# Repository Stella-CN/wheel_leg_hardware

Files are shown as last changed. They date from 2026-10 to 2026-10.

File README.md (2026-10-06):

# wheel_leg_hardware — 轮腿机器人硬件工程

本工程保存完整机器人机械与电气结构、CAD 源文件、加工/打印文件、采购制造 BOM、装配说明、验证记录和生成工具。2026-10-06 从 `wheel_leg_mujoco` 拆分；保留各阶段最终交付与必要来源，过程临时文件已清理。

## 获取仓库

本仓库使用 Git LFS 保存大于等于 10 MiB 的现有 CAD、制造包等文件，并通过 Git 子模块固定两个电机资料库的版本。请先安装 Git 和 Git LFS，再执行：

```bash
git lfs install
git clone --recurse-submodules https://github.com/Stella-CN/wheel_leg_hardware.git
cd wheel_leg_hardware
git lfs pull
```

已有克隆可运行 `git submodule update --init --recursive` 补齐电机资料。子模块来自 Gitee，需要能够访问对应服务。完整工程包含数 GiB 数据；建议按上述方式克隆，以取得 LFS 实体文件和子模块内容。

查看设计从下方 V8.3 整机 CAD、打印试装包和装配说明开始。编辑 `.FCStd` 使用 FreeCAD；STEP/STL 用于几何交换与制造准备。生成工具还涉及 Python、FreeCAD Python API 和 Node.js，具体依赖见 [依赖说明](docs/DEPENDENCIES.md)。

## 当前工作入口

| 内容 | 入口 | 用途 |
| --- | --- | --- |
| V8.3 整机 CAD | [wheel_leg_v8_3.FCStd](mechanical/v8_3/wheel_leg_v8_3.FCStd) | 当前外壳与整机结构 |
| V8.3 变化记录 | [DESIGN_CHANGES.md](mechanical/v8_3/DESIGN_CHANGES.md) | 外观与分件变更 |
| V8.3 打印试装包 | [README](mechanical/v8_3_print_trial/README.md) | 打印清单、标准件采购及试装注意事项 |
| 整机装配 | [MODULE_ASSEMBLY.md](mechanical/v8_3/MODULE_ASSEMBLY.md) | 模块预装及总装 |
| 电气集成 | [ELECTRICAL_INTEGRATION.md](mechanical/v8_3/ELECTRICAL_INTEGRATION.md) | 电气设备安装与接口 |
| 关节配合 | [LEG_FITS.md](mechanical/v8_3/LEG_FITS.md) | 腿部装配配合 |
| 硬件 BOM 数据 | [bom_master.json](mechanical/v8_3/bom_master.json) | 结构化采购与制造数据 |
| V8.2 电气基线 | [mechanical/v8_2](mechanical/v8_2/) | 电气布置、走线、集成审查与 BOM |

V8.3 试装包包含原金属件的塑料试装版本，使用边界以包内说明为准；不是承载行走的最终制造包。版本号表示设计演进，不代表所有版本通过相同验证。

## 目录与版本

```text
wheel_leg_hardware/
├── mechanical/
│   ├── v1/ … v8/            # 历代设计、CAD、制造文件及验证记录
│   ├── v8_1/                # 模块化/电池集成基线
│   ├── v8_2/                # 电气集成基线
│   ├── v8_3/                # 当前外壳设计与整机 CAD
│   ├── v8_3_print_trial/    # 全定制件打印试装包
│   └── *.zip / *.sha256     # 原始历版发布包及校验文件
├── tools/                   # 95 个 CAD、审查、渲染、制造、BOM 工具
├── references/              # 已收拢的电机、板卡、用户图纸和外观参考
├── configs/motors.json      # 拆分时的电机资料参数和历史 CAD 来源
├── assets/meshes/           # 旧电机 STEP 转换网格，非当前仿真依赖
└── docs/                    # 工具/依赖说明及拆分校验清单
```

保留 `mechanical/<版本>` 和 `tools/` 的相对层级，使既有构建、版本继承与打包脚本继续按工程根目录定位。历版发布包、CAD、BOM、数值审查报告及其哈希未重写；活动工具路径及 Markdown 手册链接已适配本地资料；报告里的原绝对路径属于历史来源记录。运行工具请使用根目录 `tools/`，各版本 `source/` 中的脚本属于当时的来源快照。

各阶段最终预览、装配图和最终报告引用的证据属于交付内容，予以保留；临时工作区、自动备份、日志、迭代诊断及重复 BOM 输出已删除。正式 BOM 位于对应版本目录。

## 使用与依赖

- [工具分类与运行说明](docs/TOOLS.md)
- [资料依赖和验证范围](docs/DEPENDENCIES.md)
- [迁移前逐文件 SHA-256 清单](docs/migration_manifest.json)
- [过程文件清理记录](docs/cleanup_manifest.json)
- [拆分后的校验结果](docs/split_validation.json)

MuJoCo 仿真继续位于 [wheel_leg_simulation](https://github.com/Stella-CN/wheel_leg_simulation)。两个工程没有 Python 导入依赖或运行时目录链接。仿真尺寸、质量、惯量和控制参数保持独立快照；硬件修改后需另行评估并同步仿真参数，不应直接用制造 CAD 替换仿真碰撞/惯量模型。

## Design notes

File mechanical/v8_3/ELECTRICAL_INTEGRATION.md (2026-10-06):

# V8.2 电气集成与线束接口

本文件解释用户接线图，并约束机械布置。电池为已确认的 WHEELTEC E626S；顶部 M16 开关为自锁型；24→19 V 模块按用户给出的 58×25×20 mm 总包络安装。新增 104×30×10 mm 四口 USB-A 扩展坞，四个下行口向机器人背部露出，充电口位于背视右下角。腿部机构不变。

这里给出功能连接关系，**不是已经核对引脚的制造接线图**。用户提供的 `3D_PCB1_2026-09-28.step` 只能确认外形、孔和连接器包络，不能证明铜箔网络、正负极、载流量或两个 CAN 通道互相隔离。必须按原理图/网表或断电通断测量确定板端线序。

## 电源拓扑

1. 电池 DC 充放共口接一分二线束。一支接后部充电母座，位于总开关之前；另一支通过顶部自锁总开关接负载分配。后部充电座在总开关关闭时仍与电池相连。
2. 开关后的电池母线分为电机支路和计算机支路。六个电机在电气上并联到电池正负母线；髋→膝→轮的画法表示线束沿腿顺次布置及 CAN 总线顺接，不表示三个电机串联分压。
3. 计算机支路经 24→19 V 模块接 Jetson 的 DC 输入。Jetson 端为 **5.5×2.5 mm**，电池端为 **5.5×2.1 mm**，不能混用内孔尺寸。线束正负极分别核对，不能仅按插头外形判断。
4. USB2CAN、IMU、相机和扩展坞通过 USB 获得低压供电及数据。屏幕以 USB 5 V 供电/触摸，视频通过 DP→HDMI。**不把电池电压接到 USB2CAN 的 GH1.25 CAN 口或 Type-C 口。**

达妙双路模块手册第 3–4 页明确：Type-C 用于供电和上位机通信；两个 GH1.25 2P 为 CANH/CANL；GH1.25 3P 为 UART；拨码开关接入每路 120 Ω 终端电阻。[达妙官方双路资料](https://github.com/dmBots/dm-tools/tree/master/USB2CANFD_Dual)

## Jetson 端口分配

以下是装配用端口分配方案，不是操作系统设备编号。为保留背部扩展坞四口给外接设备，内部设备不占用这些外露口。

| 主机接口 | 连接对象 | 线缆/说明 |
|---|---|---|
| Type-A，正Y双层座下口 | D435 | USB 3.x A→C 数据线，机内直连；模型口中心约Y9.6/Z43.6 mm |
| Type-A，负Y双层座上口 | USB2CANFD Dual | USB A→C 数据线；模型口中心约Y−7.4/Z52.2 mm |
| Type-A，负Y双层座下口 | 5 寸 GK-HD | USB 数据及供电；触摸以采购版本为准；模型口中心约Y−7.4/Z43.6 mm |
| Type-A，正Y双层座上口 | 四口扩展坞上行 A 插头 | 原150 mm线加250 mm USB3 A公→A母延长线；模型口中心约Y9.6/Z52.2 mm |
| Type-C，Host 模式 | HI13R2-USB | 优先短 C→C 数据线；需实测枚举。若实物线/设备不支持 C→C，改用合规 C→A 主机转接加原配 A→C 线并重新校核包络 |
| DisplayPort | 5 寸 GK-HD HDMI | DP→HDMI 线/转接器，需留转接头空间 |
| DC 圆孔 | 24→19 V 输出 | 5.5×2.5 mm 插头，极性和线序按实物核对 |

Jetson 官方指南确认：两个双层 Type-A 座共四口，**每一个双层座的 VBUS 合计限制为 3 A**；Type-C 可作 Host/Device/Recovery，但不提供显示输出。整机只提供 DisplayPort 视频输出，HDMI 屏需转换。每座 3 A 是载板限制，不意味着扩展坞每口可用 3 A，也不保证未知扩展坞及上行线的总供电能力。维护刷机时，断开 Type-C 上的 IMU，再连接刷机主机。[NVIDIA 硬件布局指南](https://docs.nvidia.com/jetson/orin-nano-devkit/user-guide/hardware_layout.html)

D435 接口为 USB-C 3.1 Gen 1，本版给其保留直连 USB 3.x 路径。仅凭扩展坞图片不能确定该坞是 USB 2.0 还是 USB 3.x，不能承诺其带宽。[RealSense D435 官方规格](https://www.realsenseai.com/products/stereo-depth-camera-d435/)

HI13R2-USB 使用内部 UART→USB，供电 4.5–5.5 V；规格书表 11 的 300 mW 位于最大值列。保持原点 (0,0,85) mm，避免线缆对传感器持续施加拉力。[HI13 官方规格书](https://download.hipnuc.com/datasheets/hi13_datasheet_cn.pdf)

屏幕用户规格书第 2 页标记 USB5V、HDMI；第 4–6 页说明 USB 供电/触摸和 HDMI 视频。规格书的“5 V、电流 >1 A”是通用供电排查要求，不能代替本台 5 寸屏最大工作电流实测。

## 左右腿 CAN 与动力线

| 总线 | 功能布线顺序 | 终端配置 |
|---|---|---|
| CAN 通道 1 | 双路板 → 左髋 J4310 V1.1 → 左膝 J4310 V1.1 → 左轮 H6215 | 双路板近端 120 Ω；轮端总线末端 120 Ω；中间节点无终端 |
| CAN 通道 2 | 双路板 → 右髋 J4310 V1.1 → 右膝 J4310 V1.1 → 右轮 H6215 | 同上，独立于通道 1 |

J4310 V1.1 手册第 8 页允许双 XT30(2+2) 接口顺接电机；电源和 CAN 共用连接器但属于不同电路。末端 H6215 的终端电阻是否已集成，必须检查实物/厂商资料，不能重复加装。图中“J430”按现有装配实际型号 J4310 处理。

高速 CAN 采用两端各 120 Ω；所有设备断电后，理想等效 CANH-CANL 约 60 Ω。每条 CAN 总线分别测量，不把左右 H/L 并到同一网络。[TI CAN 物理层与终端说明](https://www.ti.com/lit/ds/slls632c/slls632c.pdf)

建议初始采用电机现有兼容 CAN 2.0 波特率 1 Mbps；不因 USB2CAN 支持 CAN FD 而自行将电机链路切成 FD。每条总线上配置唯一节点 ID。双路适配器的通道映射按设备序列号/物理通道固定，不能只凭 Linux 首次出现的 `can0/can1` 名称识别左右腿。此版未刷写固件或修改控制软件。

## 装配与布线要求

- 顶部开关按插接座后总深度 **47.5 mm** 保留安装空间；端子绝缘和拔插空间另计。螺母固定面可用扳手接近，不能只校核 Ø16 开孔。
- 扩展坞用可拆压托固定，夹持壳体，不用 USB 插座承受固定载荷。四个口用一个公共长窗口露出，避免把未经实测的单口位置当精确开孔基准。150 mm 上行线不能支撑现有绕行路线，增加一根250 mm USB3 A公→A母数据延长线，侧后方对接并固定余线；组合长度不是实际线束成品长度，需按实物弯曲复核。插头26 mm包络及插拔区单独校核。
- 扩展坞不可拆线从电子盘后缘7 mm宽U形开口槽侧向放入，槽中心X−75/Y25；不假设模塑USB插头能穿过圆形小孔。服务架X70/Y21增设Ø8.6穿线孔；孔口去毛刺，端头与整束能否穿过仍按实际线缆检查。
- 扩展坞上表面加两片2×15×0.5 mm软垫，最终压缩厚度按0.5 mm间隙试配。位置X−63..−61、Y中心±35、Z10..10.5 mm；仅接触非端口外壳边，不将软垫贴到插座上。
- 后部 DC 母座置于可更换接口板；当前尚无母座螺纹/开孔图，中央应保留可后加工区域，不能将电池 5.5×2.1 的插合尺寸当面板开孔尺寸。
- 动力线随机体边缘布置，正负导线成对；USB、DP/HDMI 和 CAN 双绞线走独立束组，避开 DC/DC 热区和风扇进出风口。两侧机壳出线孔为Ø10、板厚3 mm，中心X89/Z54 mm；另有托盘Ø10过线孔。选配护线套要求适配板厚且有效净孔至少7 mm，实际能否容纳整束需实测；不能将外孔径当作护线后净孔。具体轨迹以本版 CAD 路由为准，间距预留不是 EMC 认证。
- 从机身到两腿的线束在静止侧及运动侧分别作应力释放，中间保留运动弯折环；不得跨越 OB/OA 嵌套槽、轴承、轮胎或运动限位面。检验完整行程及多次屈伸，线缆最小弯曲半径以实际线材厂商数据为准。
- 模块接插件及线缆标注 BAT、CHG、MOTOR-L/R、DC-IN/19V-OUT、CAN1/2、CAM、IMU、SCREEN、HUB。拆后盖前先断电池，再拆后盖关联插头；后盖不能靠拉线悬挂。
- 先将电子盘、板架、线束预装成模块，再安装到机身；供电首次连接前完成极性、短路、绝缘及两路 CAN 终端测量。紧固螺钉/金属支柱不得接触 PCB 带电焊盘；不能凭外壳 STEP 判断铜箔净空。

## 当前电气边界

| 项目 | 已知 | 尚需验证及影响 |
|---|---|---|
| E626S | 22.2 V 标称、25.2 V 满充、18 V 截止；6 A 持续、13 A 瞬时 | 瞬时时长未给。整机负载与接插件压降需实测，不能由电机相电流直接求电池电流 |
| 顶部自锁开关 | M16；图示 10 A/250 VAC | 未给直流分断、触点电流及 LED 电压。尚不能确认可直接开断电池主回路；不得由 AC 标称外推 DC 能力 |
| 24→19 V 转换器 | 总长 58、宽 25、高 20；孔距 51、孔 Ø4 | 输入范围、功率、电流、效率、发热、低压行为未知；机械模型不等于电气选型完成 |
| Jetson 电源 | 19 V 目标；开发套件 DC 输入 9–20 V，DCJ_IN 最大 4.2 A | 电池满充 25.2 V 不能直连。转换器输出瞬态也应处于输入允许范围 |
| J4310 V1.1 | 手册 p7：24 V 版推荐 24–28 V，最低 20 V、最高 28 V | 同份 p6 保护表另写不低于 15 V，存在不一致；本次按更严格的 **20 V 最低** 作集成约束，待厂家澄清。22.2 V 已低于推荐范围，需实测降额性能；不能运行到电池 18 V 截止才处理 |
| 后部充电口 | 电池为 DC5.5×2.1 充放共口；总开关前引出 | 所选面板座开孔、载流、极性和原配充电器未给。优先关机充电；未验证边充边用及倒灌路径 |
| 分配 PCB | 用户提供外形 STEP | 原理图、PCB 铜厚/线宽、保险/保护、端子额定值、CAN 走线网络均未确认 |
| USB 外接负载 | 四口扩展坞、150 mm 一体上行线 | 产品型号、速率、总功耗/限流未知；外接 SSD 等负载需计入 19 V 转换器及电池预算 |

电池数据来自[WHEELTEC 官方 24-DC 说明书第 12 页](https://wheeltec.net/24-DC.pdf)。Jetson DC 范围与 4.2 A 由[NVIDIA 官方工程师对载板规格的说明](https://forums.developer.nvidia.com/t/power-supply-for-jetson-orin-nano/362326/5)核实；完整规格文件本次网页访问受限，不把论坛引述误写成已完整检查 PDF。

若该转换器只有降压能力，电池电压接近/低于 19 V 时不能保证稳定 19 V 输出；不能仅凭“24→19 V”标签证明覆盖 E626S 全放电范围。且腿电机的最低供电约束更高，应先以电池**带载电压**和厂商最低工作电压定义停机阈值与余量，再决定转换器是否需要升降压。

按电池标称电压，持续电功率上界为 22.2×6=133.2 W；已知四台 J4310 同时在 3 N·m、120 rpm 时，仅轴端机械功率已约 150.8 W，尚未计驱动损耗、轮电机、Jetson、屏幕及外接 USB 负载。**此电池不能据此宣称支持六电机同时额定运行或跳跃。** 机械布置完成后，应进行实际任务工况电流、母线跌落、再生制动过压、开关分断和连续温升试验，校正电源与线束选型。

## 本版证据与交付范围

- 配套拓扑：`WIRING_TOPOLOGY.svg`，适于说明装配功能关系，颜色区分电池母线、19 V、CAN、USB 和视频。
- 达妙原始手册保留于用户 `references/dm-tools/USB2CANFD_Dual/`；本版 `source/electrical/usb2can_manual.txt` 为文本检索副本，`usb2can-03.png`、`usb2can-04.png` 为已目视核对页。
- `source/electrical/j4310_v11_manual.txt` 来自指定 V1.1 驱动手册 V1.2；不使用 V1.2 驱动替代其电气参数。
- 图纸未标的线序、额定电流、插头位置、最小弯曲半径都保持待验证；本文件没有凭 STEP 生成导电网络，也没有新增未经选型的主电源电子开关或保险规格。

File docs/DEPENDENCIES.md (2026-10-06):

# 依赖与验证范围

## 已收拢的资料

| 工程内位置 | 处理方式 |
| --- | --- |
| `references/DM-J4310-2EC/`、`references/DM-H6215/` | 从同级共享资料目录复制；仿真仍引用原资料来源，原目录保留 |
| `references/dm-tools/USB2CANFD_Dual/` | 从同级共享资料目录移动 |
| `references/user_supplied/3D_PCB1_2026-09-28.step` | 从 Downloads 移动 |
| `references/user_supplied/wheel_leg.png`、`wheel_leg_front.png` | 从 Downloads 移动 |
| `references/user_supplied/*user_drawing.png` | 临时剪贴板原图已不存在，从已保存的版本来源副本恢复 |

逐文件来源、目标、复制/移动方式和 SHA-256 见 [dependency_migration.json](dependency_migration.json)。当前 `tools/` 和 `configs/motors.json` 使用工程内相对路径；不读取原 Downloads、共享 references 或系统剪贴板目录。仿真不需要导入硬件工程。

## 无法恢复的历史输入

`/tmp/v82_validated_pre_routes.FCStd` 已不存在。遍历现有 CAD、FCBak 及发布 ZIP 内 CAD 后，未找到符合原报告 SHA-256 的文件：

```text
d35408105a0689bd59c183aedc95a6e91b170502f41906df2e71bff9944febaa
```

`tools/review_v82_final_delta.py` 因此不能重跑完整历史差异审查；如找回原文件，应放到 `references/audit_baselines/v82_validated_pre_routes.FCStd`。不使用当前 CAD 冒充原基线。检索记录见 [baseline_recovery.json](baseline_recovery.json)。

`/tmp/v82_hub_clamp_before_clearance.brep` 原文件也已不存在，但 `mechanical/v8_2/source/validation_before_cut_USB_hub_rear_clamp.brep` 和另两件切削前几何仍在，`review_v82_final_cuts.py` 优先读取这些已保存几何。仅当它们缺失、需要重新提取时，才需要上述完整基线和 `references/audit_baselines/v82_hub_clamp_before_clearance.brep`。

## 软件环境

按用户要求，软件保留原安装位置，不搬移或打包系统运行库：

- CAD：`/Applications/FreeCAD.app/Contents/Resources/bin/python`，以及 `Part`、`Mesh`、`MeshPart`。
- 渲染：FreeCAD GUI、Qt/PySide 和本机图形环境。
- 普通分析：Python 3；部分图表工具使用 NumPy、Matplotlib，按脚本导入配置。
- BOM：Node.js、`@oai/artifact-tool`；原工具使用 `~/.cache/codex-runtimes/codex-primary-runtime/dependencies`。工具重跑时会在临时工作目录链接该公共运行库，原临时目录已清理。
- 硬件工程不依赖 MuJoCo、仿真 `.venv` 或 `wheel_leg` 包。

## 清理策略

已删除 `tmp/`、`mechanical/workbench/`、字节码缓存、FreeCAD 自动备份、过程日志、工作簿中间检查以及未被最终报告使用的迭代诊断。`outputs/` 两份 BOM 与对应版本正式工作簿逐字节一致，因此删除重复输出。清单及删除前哈希见 [cleanup_manifest.json](cleanup_manifest.json)。最终预览、报告直接引用的证据和工具必需的基线保留。

## 历史记录与验证边界

原发布 ZIP、各阶段最终 CAD、BOM 数据、源脚本快照及最终数值审查结果保持不变；活动工具的本地资料路径和部分 Markdown 手册链接已更新。历史来源记录中的绝对路径保留用于追溯。版本 `source/` 中的脚本及 ZIP 是原始快照，不是本次适配后的运行入口。

旧打包工具中针对源代码哈希的冻结检查可能因本次路径修改而拒绝重新发布旧版本。这是正确的审计行为；没有修改旧验证报告来绕过检查。重新构建和发布应重新验证并生成新的版本证据。

拆分验证涵盖逐文件 SHA-256、链接目标、仿真原有 21 项测试、单腿/双腿模型检查、三份 MJCF 加载、硬件活动脚本语法及转换器本地来源解析。结果见 [split_validation.json](split_validation.json)。没有重生成各版 CAD、制造包或工作簿；这次文件拆分不构成新的结构强度、电气或实物装配验证。

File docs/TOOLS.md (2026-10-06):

# 工具分类与运行

所有命令从 `wheel_leg_hardware` 根目录执行。实际参数以对应脚本的 `--help` 或文件头说明为准；构建与打包会写入对应版本目录，应在需要重生成时运行。

| 工具类别 | 脚本 | 输出/作用 |
| --- | --- | --- |
| CAD 建模 | `build_*robot.py`、`cad_*.py` | 历版整机及零件结构 |
| V8.2 电气 | `build_v82_electrical.py`、`finish_v82_electrical.py` | 电气集成及导出 |
| V8.3 外壳 | `build_v83_shell.py` | 当前外壳与装配 |
| 几何、安装审查 | `review_*.py`、`inspect_*.py` | 接口、干涉、安装和版本差异 |
| 质量与负载 | `analyze_*.py` | 质量预算、机构比例、电机负载 |
| 渲染与图示 | `render_*.py`、`draw_*.py` | CAD 预览、接口与走线图 |
| 制造导出 | `export_*.py`、`orient_*.py`、`validate_*meshes.py` | STEP/STL、打印姿态和网格验证 |
| 打包 | `package_*.py` | 历版发布包与哈希 |
| BOM | `build_*bom_data.py`、`build_*bom.mjs` | BOM 数据与采购制造工作簿 |
| 历史电机网格 | `convert_cad_models.py` | 从工程内参考 STEP 转换到 `assets/meshes/` |

查看历史电机转换选项（只需 Python 标准库）：

```bash
python3 tools/convert_cad_models.py --help
```

转换需要 FreeCAD 或其 Gmsh，电机来源读取 `configs/motors.json`，不再导入仿真工程。

FreeCAD 构建脚本沿用 macOS 安装路径，例如：

```bash
/Applications/FreeCAD.app/Contents/Resources/bin/python tools/build_v83_shell.py
```

运行前阅读 [依赖说明](DEPENDENCIES.md)。部分渲染需要 FreeCAD GUI/Qt；不能用普通 Python 代替 FreeCAD Python。BOM `.mjs` 工具使用 Node.js 和 `@oai/artifact-tool`，文件头列出输入输出参数；原脚本从用户目录的 Codex runtime 加载依赖。

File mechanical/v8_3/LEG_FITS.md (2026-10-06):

# V8.1 腿部配合与首件验收

单位mm。下列为单台样机的工程加工/装配目标，需在加工图上标注；CAD表达名义尺寸，不能用STL网格作为精密配合尺寸依据。任何涂层厚度均应计入最终尺寸，轴承座、止口、压盖座及螺纹不得喷厚漆。

## 关键配合

|位置|名义结构|加工与验收要求|
|---|---|---|
|A/B/C轴承外圈|626ZZ1，Ø19座，压盖防脱|孔Ø19 H7作为可拆首件基准；测实际轴承外径，禁止敲打滚动体。运行后检查外圈爬动，动态载荷下是否需要过渡配合/可拆固持剂须另行验证。|
|关节轴/轴承内孔|D6钢轴；轴承内径名义6|先量采购轴承，再精磨轴工作段，实测直径间隙目标0.003～0.010；不能仅用名义“D6”保证装配。圆柱度、两端同轴度各≤0.005，倒角不得顶到轴承内圈。|
|铜套/叉耳|耳孔名义Ø8，套外圆Ø8|根据单台实际耳孔选配0.005～0.010轻过盈；不得把“H7孔+任意m6套”当成必然合适。薄耳支撑就近，压后复测内孔6.03～6.06。铜套压装时托住叉耳、推铜套端面。|
|双叉同轴|OA-A、CW-C及OB-B|两个铜套安装后，用通轴验同轴；目标≤0.02。OB内/外件按配对编号，必要时在装配夹具中组合精加工轴孔。D50止口有间隙，不能单独承担B孔精确同轴定位。|
|轴销轴向长度|L14.05；支承有效端面跨度14.00|轴销L14.05±0.01，实测对应支承端面跨度14.00±0.01；轴销相对支承的防夹死余量目标0.03～0.07。两端0.20挡片装后，应夹住销端面而非把双叉向内拉弯。|
|轴承内圈间距|叉内距9.00；内肩1.25＋轴承6＋外肩1.70|名义余隙0.05；实测装配目标0.03～0.10。先测轴承宽B和叉内距F，再以 T外=F−B−T内−目标余隙 修磨外侧肩，记录A/B/C各自实测值。1.70是名义值，不是假定厂商轴承宽度无公差。|
|轴承外圈轴向保持|轴承座底8.75，压盖下面14.80（相对膝定子面）|名义外圈余隙0.05；实物检查目标0.03～0.20，压盖仅挡外圈、不摩擦密封盖/内圈。超界应先核实轴承及局部台阶，不可把压盖强拧成预紧弹片。|
|髋法兰套接|公件Ø43，母件Ø43.05，嵌合7|公件43.000/−0.015，母件43.050/+0.015，直径余隙0.050～0.080；端面平面度0.03、对轴线垂直度0.03。四个径向螺钉负责锁紧，不靠强压过盈装拆。|
|D4定位销|DIN6325 4m6×10，3/侧|法兰孔4H7过渡配合，孔位置按实物电机/检具确认。原厂电机孔4.02～4.04；三销必须可同时对合，不可用螺钉强拉。只用挡块控制法兰插入7.00±0.05；实际外露长度随标准销长变化。|
|O处定位/导向|OA鼻Ø35，外壳孔Ø35.4；D50/D50.2|均为间隙嵌套，不作为钢轴承替代。鼻35.000/−0.02，孔35.400/+0.03，运行前验全行程不接触；外壳/内框止口直径余隙目标0.15～0.25。|
|轮辋与轮轴止口|V8 Ø33.05配原厂Ø33|以实物原厂止口测量匹配，直径间隙目标0.03～0.07；螺钉交叉拧紧后检端面贴合、轮辋端跳/径跳。轮胎另有弹性，不能以网格外形判断动平衡。|

内外带肩衬套属于两种名义车削件：内侧套段2.50、肩1.25，总长3.75；外侧套段2.50、肩1.70，总长4.20。套段朝耳孔，肩朝轴承。外侧一体化后肩从14.80开始，轴承名义外端14.75，保留0.05余隙；原方案的游隙位于隔圈与耳面之间。本版将其移到内圈与肩之间，轴承/叉耳位置不变。

单台选择装配意味着最后修磨过的铜套应按A/B/C编号保存，而不是宣称所有成品都可不测量互换。肩OD8.4与套OD8的环形止口面积仅 **5.15 mm²**；它用于轻压装的几何定位，不作为高预紧力的承压面。肩与轴承内圈接触环的几何面积约25.23 mm²，仍需按具体轴承端面/倒角确认接触，不能让肩碰防尘盖。

## 轴销内孔与标准螺钉长度

D4定位销的长度有公差，[Ganter DIN6325目录](https://www.ganternorm.com/en/products/New-products/New-products/DIN-6325-Dowel-Pins-Steel)标为js14；“插入7＋外露3”只是名义尺寸，不能同时当作两个独立精确尺寸。入厂按实际长度9.75～10.25验收，控制法兰插入6.95～7.05，法兰平底有效孔深7.20±0.05；则销向电机外露2.70～3.30。对STEP给出的4 mm电机孔深，最少余0.70；对法兰盲孔，最少余0.10。深度靠夹具控制，不能压到孔底再假定伸出3 mm。

双端M2有效牙深改为≥4.30，圆柱底孔深4.60（平底有效深度，不包括任意新增钻尖）。保持轴销外形D6×14.05。名义中间实心长度14.05−2×4.60=4.85；按轴长14.04、两端孔深各4.65最不利组合，仍有4.74实心段。采用普通钻尖时必须将尖端额外长度加入复核，不得直接以平底数值判合格。

SETS-M2-4隔0.20挡片后名义进入销端3.80。首件采购检验螺钉头下长≤4.20、挡片厚≥0.18时，最深进入4.02，小于4.30完整牙深，名义余量不依赖螺纹顶底。压盖用途的M2螺钉夹持0.80、名义啮合3.20；确认铝件完整牙深≥3.40。两个用途仍使用同一个SETS-M2-4 SKU。

|连接|每侧数|采购长度|名义夹持/啮合|螺孔深度/余量|
|---|---:|---|---|---|
|髋转子法兰→髋转子|6|ISO4762 M3×8|5/3|原厂孔深5，余2|
|定子杯→膝后定子|4|SLH M3×6|2.5/3.5|原厂孔深4，余0.5；最敏感，应先实测孔深和螺钉长度|
|法兰侧向锁紧|4|SLH M3×8|4.8/3.2|完整牙≥3.5；底孔带尖端需保留余壁|
|OB内框→膝前定子|6|SLH M3×6|2/4|原厂孔深5，余1|
|OA→膝转子|6|ISO4762 M3×16|12/4|原厂孔深5，余1|
|CW→轮电机定子|3|ISO4762 M3×8|5/3|原厂孔深5，余2|
|轮辋→轮电机转子|6|ISO4762 M3×8|4/4|原厂孔深5，余1|
|OB内框→外包壳|4|DIN7991 M3×10（含头总长）|3/7|底孔从偏置2.9至11.1；首件核查完整牙≥7.3|
|髋座→髋定子|6|DIN7991 M3×6（含头总长）|3/3|原厂孔深5，余2|
|髋座→机身|4|DIN7991 M4×12（含头总长）|两金属面＋0.8垫＋3.2螺母|名义突出螺母2.2；不换厚锁紧螺母而仍宣称螺钉长度适合|

其中3.5 mm膝后螺纹啮合只有0.5 mm名义孔底余量。应记录实际螺钉长度、杯壁厚度、螺孔有效深度，验最不利组合仍有≥0.2 mm余量；不合格优先选同标称6 mm合格长度的螺钉，不用盲目加力。电机螺纹强度和装配扭矩以实物版本/供应商意见及样机验证为准。

## 制造与验收边界

- 负载主臂、两法兰、髋座和轮辋均采用6061-T6 CNC/车铣，不改用PETG。AC虽然轮廓像平板，但有轴承台阶及压盖座，不能只激光下料就当成完成件。
- 压盖可精密钣金/激光切割并去毛刺整平；0.2防脱挡片是定制精密钢片，不能拿普通M2小外径平垫替代。
- 一体带肩衬套减少12个散件及一个名义定制SKU，但不能因此增加轴承预紧。装后以手动自由运动、轴向游隙和温升/磨屑检查确认。
- 6个轴承的负荷分配、钢销疲劳、铝耳孔承压、螺纹拔出及落地冲击仍未完成强度试验。本版局部CAD通过三姿态几何检查；整机姿态/装配检查见总报告。几何无碰撞不等于已验证跳跃能力。

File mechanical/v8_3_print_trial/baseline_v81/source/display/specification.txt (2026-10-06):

产品总体介绍： 产品是一款支持高清 IPS 显示，内置立体声喇叭，

支持多系统，多设备，金 属外壳设计，接口内缩设计的高端显示器。

用料十足。可连接电脑笔记本，树莓 派，香橙派，机顶盒，监控器，

打印机等，功能非常强大

5 寸显示器尺寸图：

7 寸显示器尺寸图：

10 寸显示器尺寸图：

配件选购：

基本功能操作：

A: hmdi 连接好你的设备比如电脑，然后再接另外一头接到显示器

的 hmdi 口 B: usb 供电线连接到适配器或者电脑都可以供电，再接

到显示器的 usb 口

7. 设备支持 台式机电脑，笔记本电脑 树莓派开发板全部系列包括

2B3B4B5B 等 香橙派开发板包括 2W 3B PI5 等 Linux 开发板包括品

牌正点原子野火韦东山等 打印机设备，监控器，照相机 直播设备，

工业应用 泰山派开发板，安卓开发板 电视机顶盒。等

系统支持： Windows 7/8/9/10/11 Linux，ubutun， 树莓派系统 香

橙派系统 安卓系统

使用问题排查

树莓派： 1. 树莓派无显示问题或者闪屏问题： A:检查下显示器是

否正常供电，树莓派供电输入是否满足 5V2A，排查适配器或者 电脑

供电不足问题 B:检查下 USB 线给显示器的是否损坏或者没有插好，

多试几次，或者换一根线 C:检查树莓派系统是否烧录有问题导致，

换个系统烧录试试或者，你的 SD 是否 有问题，检查 SD 卡是否损

坏了导致系统不能启动。 D:分辨率设置问题：请判断你的系统是否

支持分辨率 1024X600 或者 800X480, 如果没有可以自己设置，不会

可以咨询开发板的卖家告诉你怎么设置，他们知道 方法。 E:检查下

hmdi 线有没有完全插进去设备的接口，检查你的设备接口是不是损

坏 生锈进水坏掉了

树莓派有显示无触摸问题 A: usb 线要插在开发板中间一排的 USB

才支持触摸功能 B: 检查下显示器是否正常供电，树莓派供电输入是

否满足 5V2A，排查适配器或 者电脑供电不足问题 C: 检查下 USB

线给显示器的是否损坏或者没有插好，多试几次，或者换一根线。

香橙派： 1. 无显示问题或者闪屏问题 A:检查下显示器是否正常供

电，开发板供电输入是否满足 5V2A，排查适配器或者 电脑供电不足

问题。 B:检查下 USB 线给显示器的是否损坏或者没有插好，多试几

次，或者换一根线 C:检查 SD 系统是否烧录有问题导致，换个系统

烧录试试或者，你的 SD 是否有问 题，检查 SD 卡是否损坏了导致

系统不能启动。 D:分辨率设置问题：请判断你的系统是否支持分辨

率 1024X600 或者 800X480, 如果没有可以自己设置，不会可以咨询

开发板的卖家告诉你怎么设置，他们知道 方法。 E:检查下 hmdi 线

有没有完全插进去设备的接口，检查你的设备接口是不是损坏 生锈

进水坏掉了。

2. 无触摸问题 A: usb 线要插在树莓派开发板蓝色支持通信的口 B:

检查下显示器是否正常供电，开发板供电输入是否满足 5V2A，排查

适配器或 者电脑供电不足问题 C: 检查下 USB 线给显示器的是否

损坏或者没有插好，多试几次，或者换一根线

其他设备问题综合排查： 显示问题： 主要检查给显示器供电是否满

足设备电压 5V, 电流>1A，

检查下 hmdi 线有没有完全插进去设备的接口，检查你的设备接口是

不是损坏生 锈进水坏掉了 检查你的系统是否支持分辨率 1024X600

或者 800X480 触摸问题： 检查下 usb 线是否没有插好到设备，usb

是否损坏换一根试试，usb 线要购买支 持通信的而不是只有供电的。

检查下你的 usb 接口是不是损坏生锈进水坏掉了 ，换台电脑测试下

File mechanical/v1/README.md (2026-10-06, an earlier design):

# 双腿轮足机器人机械首版

本目录交付可加工、可切片的**低载装配审查首版**。髋—膝连接采用两片式 6061-T6 CNC 法兰，其余定制刚性零件采用 PETG 打印；电机、轴承、肩轴、金属紧固件和弹性轮胎另购。尚未完成静强度、冲击、疲劳、热蠕变或跳跃验证，不具有额定承载能力声明。

## 文件与用途

| 文件 | 用途 |
|---|---|
| [wheel_leg_v1.FCStd](wheel_leg_v1.FCStd) | FreeCAD 原生装配、采购参考件及四杆运动学表达式 |
| [wheel_leg_assembly.step](wheel_leg_assembly.step) | 含真实电机 STEP 和采购件包络的整机装配 |
| [wheel_leg_structure.step](wheel_leg_structure.step) | 全部定制结构件，保留装配位置 |
| [wheel_leg_assembly.stl](wheel_leg_assembly.stl) | 单文件、多壳体装配展示；含电机、轴承、肩轴、隔套和轮胎参考件 |
| [print/](print/) | 已放平到打印平台、原点归零的分件 STL，单位 mm |
| [step/](step/) / [cnc/](cnc/) | 分件精确实体；CNC 法兰应使用 STEP 和接口说明加工 |
| [parts.csv](parts.csv) / [part_manifest.json](part_manifest.json) | 数量、包围尺寸、封闭网格检查；质量列是按实体体积估算，未计切片填充率 |
| [INTERFACES.md](INTERFACES.md) | 电机真实孔系、接口来源、CNC 尺寸及待确认公差 |
| [validation.json](validation.json) / [joint_hardware_validation.json](joint_hardware_validation.json) | 姿态干涉与关节硬件检查结果 |
| [assembly_stl_report.json](assembly_stl_report.json) | 整机 STL 导出、回读、尺寸及范围记录 |

整机 STL 含 74 个对象、1,574,452 个三角面，文件约 75.1 MiB，外包络约 232.67×425×283.81 mm。STL 不保存材料、螺纹、关节或参数。导入切片器时选择 mm、100% 比例；**整机 STL 用于观看装配，生产请使用 `print/` 分件**。它包含互相独立、接触或嵌套的采购件网格，不应作为一个整体实体打印。

## 布局与运动

- 坐标：X 前方、Y 左右、Z 向上；髋轴位于 X=Z=0。外壳为 200×150×100 mm，中空、可拆顶盖；壁厚 3.2 mm、底厚 4 mm、顶盖厚 4 mm。
- 保留仿真的 130 mm 长杆与 35 mm 短杆中心距。每侧由固定于膝静壳的 OB、膝输出驱动的 OA、连接 AC 和输出 BCW 构成四杆；B—轮心距离为 130 mm。
- 真实电机轴向堆叠使轮距采用 380 mm，原仿真轮距为 274 mm。本次未修改原 MuJoCo 模型，也未重新标定质量、惯量和接触参数。
- 髋与膝各用一台 DM-J4310-2EC，每侧轮端用一台 DM-H6215。安装面和孔位取用户提供的原始 STEP，螺纹深度结合二维图；不能用仿真外观字段代替制造接口。
- FreeCAD 中修改 `Parameters.LegLength` 可改变腿长；已抽样检查范围为 120～225 mm、`Beta=0°`，默认约 183.848 mm。装配位置由表达式计算，**不是 FreeCAD 原生 Assembly 约束求解器**，没有接触求解或实体机械限位。任意摆角、超出范围或修改杆长后须重新验证。
- 电池包暂按 110×50×35 mm 预留；电子托盘为 188×46 mm。两者均未根据最终采购件定版。侧向电机侵入机身空间，不能把外壳整体内部尺寸当作可用电池包尺寸。

## 定制件数量

| 零件名 | 工艺 | 整机数量 | 作用 |
|---|---|---:|---|
| chassis_lower_shell | PETG | 1 | 中空底壳、侧电机窗口、金属螺母承压座 |
| chassis_lid | PETG | 1 | 拆卸顶盖与定位唇 |
| battery_tray | PETG | 1 | 电池托盘与绑带孔 |
| electronics_tray | PETG | 1 | 控制器托盘与安装长孔 |
| hip_stator_mount | PETG | 2 | 髋静壳安装板 |
| fixed_arm_OB | PETG | 2 | 膝静壳支承杆 |
| active_arm_OA | PETG | 2 | 膝输出短杆 |
| coupler_AC | PETG | 2 | 两端轴承连杆 |
| output_BCW | PETG | 2 | 输出杆与轮电机安装座 |
| wheel_rim | PETG | 2 | 弹性轮胎的支承轮圈 |
| bearing_fit_coupon | PETG | 1 | 轴承孔公差试片，不装入整机 |
| hip_rotor_cnc | 6061-T6 CNC | 2 | 髋电机输出侧半法兰 |
| knee_stator_cnc | 6061-T6 CNC | 2 | 膝电机背壳侧半法兰 |

合计：10 种功能打印件、16 件，另加 1 件公差试片；2 种 CNC 件、4 件。左右侧由同一分件翻面安装，按装配体核对各沉孔和轴承座朝向。

## 建议采购与螺钉长度

下表为按当前实体计算的首轮采购规格。螺纹啮合为名义值，电机孔内没有建模真实牙型；需按实物有效牙深和选定螺钉头下长度复核，不能顶底。除明确列出垫圈的位置外，下表电机螺钉按**不加垫圈**计算；擅自加垫圈会缩短啮合。

| 位置/物料 | 建议规格 | 数量 | 名义长度依据 |
|---|---|---:|---|
| 髋、膝电机 | DM-J4310-2EC | 4 | 使用提供的真实模型 |
| 轮电机 | DM-H6215 | 2 | 使用提供的真实模型 |
| A、B、C 被动关节轴承 | 626ZZ，6×19×6 mm | 12 | 每关节 2 个，每侧 3 关节 |
| A/C 肩轴 | 淬硬肩螺钉，肩 Ø6×25 mm，端牙 M5 | 4 | 与外侧 3 mm 钢隔套配套；不是 22 mm 肩长 |
| B 肩轴 | 淬硬肩螺钉，肩 Ø6×20 mm，端牙 M5 | 2 | 外侧头下名义位置 Y=164.5 |
| 肩轴螺母 | M5 六角螺母，对边约 8、厚约 4 mm | 6 | 六角槽对边 8.3，A/C 切槽深 5.3、B 为 4.3；螺母置靠槽内底 |
| 轴承内圈中间隔套 | 钢，内 Ø6.2、外 Ø10、长 2 mm | 6 | 放在两轴承内圈之间 |
| 内端偏置隔套 | 钢，内 Ø6.2、外 Ø10、长 2.5 mm | 6 | 固定杆与内侧轴承垫片之间 |
| 轴承内圈薄垫片 | 钢，内 Ø6.2、外 Ø10、厚 0.5 mm | 12 | 每关节两片，只压内圈 |
| A/C 外端补偿隔套 | 钢，内 Ø6.2、外 Ø10、长 3 mm | 4 | Y=181.5～184.5，适配标准 25 mm 肩长 |
| 关节调整垫片 | 钢，内 Ø6.2、外 Ø10、厚 0.1/0.2 mm | 按实测选配 | 补偿肩长和叠厚公差，只接触轴承内圈 |
| 髋静壳→安装板 | M3×8 内六角圆柱头 | 12 | 头座至电机面 5，入牙 3；PCD50 |
| 膝前静壳→OB | M3×8 内六角圆柱头 | 12 | 头座至电机面 5，入牙 3；PCD50 |
| 髋输出→hip CNC | M3×16 内六角圆柱头 | 12 | 夹持厚 11.5，入牙 4.5；PCD27，原图牙深 5 |
| 膝背壳→knee CNC | M3×6 内六角圆柱头 | 8 | 夹持厚 2.5，入牙 3.5；PCD38，原图牙深 4 |
| 膝输出→OA | M3×20 内六角圆柱头 | 12 | 头座至输出面 17，入牙 3；PCD27 |
| H6215 固定端→BCW | M3×8 内六角圆柱头 | 6 | 夹持厚 5，入牙 3；PCD17.5 |
| H6215 输出→轮圈 | M3×8 内六角圆柱头 | 12 | 夹持厚 4，入牙 4；PCD28，按新版二维图牙深 5 |
| 两片 CNC 法兰连接 | M4×10 内六角圆柱头 | 8 | 从 knee 外侧穿过 6 mm，啮合 hip M4 螺纹 4 mm；PCD68，**不装内侧螺母** |
| 两片 CNC 定位销 | Ø3 钢销，名义长 10 mm | 4 | 双片总厚 12；销/孔实际配合需加工方确认 |
| 髋安装板→底壳 | M4×25、90°沉头螺栓（DIN 7991）、M4 螺母、内侧金属垫圈 | 8 套 | 总长含沉头；板外面至内承压面18.2，内侧约0.8垫圈+3.2螺母，名义余约2.8 mm；外侧头须齐平，不加垫圈 |
| 顶盖→底壳 | M3×8 | 8 | 穿盖 4，啮合嵌件约 4 |
| 两托盘→底壳 | M3×6 | 8 | 穿耳/板 3，啮合嵌件约 3 |
| 底壳热熔嵌件 | M3、长度不超过 5 mm，匹配 Ø4.2 安装孔 | 16 | 顶盖 8、电池托盘 4、电子托盘 4；按具体嵌件厂商孔径校准 |
| 弹性轮胎 | 外 Ø100、内 Ø86、宽 32 mm | 2 | 采购/定制橡胶或弹性材料；非 PETG 实心胎 |
| 电池绑带 | 宽度不超过 10 mm | 2 | 通过托盘槽孔；另备线束固定件 |

M3 圆柱头应能放入对应 Ø5.8/Ø6.2 沉孔；沉孔深度和扳手伸入空间以实购件复核。建议表不包含电子板支柱、最终电池/控制器、线束接头或线缆护套。肩轴小肩台直接压在PETG上，不能套用普通M5钢连接的锁紧扭矩；采用受控轻夹紧和适合材料的防松方式。肩轴参考 [Ganter ISO 7379 官方规格](https://live-katalog.ganternorm.com/pdf/ganter/EN/7379.pdf)：Ø6/M5 端牙长 9.5 mm、头 Ø10×4.5 mm，肩长允许正偏差 0.25 mm。用 0.1/0.2 mm 钢薄垫片按实测调整叠厚，核对螺母完整啮合、端部伸出和肩根退刀槽；夹紧后关节应顺畅转动、无轴向松旷，不能靠压紧 PETG 来调整轴承预载。

## 打印与加工

打印基线：220×220×250 mm 平台、0.4 mm 喷嘴、0.2 mm 层高、PETG、6 道外墙、8 层顶/底、40%～60% 填充。轴承座、肩轴固定区、电机螺钉座建议局部100%填充；最终参数应结合材料和设备校准。分件包围盒均能放入指定平台，最大壳体平面 200×150 mm；裙边、支撑和清理塔仍需在切片器内检查。

1. 先打印 `bearing_fit_coupon.stl`；沿 100 mm 长边从小 X 到大 X，四孔依次为 Ø19.00、19.10、19.15、19.20 mm。用实际 626ZZ 试配，选择轻压入且不裂的孔径；当前轴承座名义 Ø19.15。不要通过改变全零件缩放率修正孔径，应修改参数后重建。
2. 分件 STL 已按打印方向放平：底壳/托盘底朝下，顶盖外表面朝下，杆件大面贴平台、主要孔轴竖直。侧开口、底壳顶端悬空螺钉座、托盘抬高耳部，以及切片预览中未被支撑的局部台阶需局部支撑。清理支撑后复查孔径和平面。
3. 固定孔通孔可按实物轻量修整；轴承座不可在没有同轴基准时随意手钻扩孔。热熔嵌件先在同材料余料试装，确认不顶底、不撑裂、不突出接触面。
4. CNC 件按 [接口说明](INTERFACES.md) 和 STEP 审查加工。hip 外圈是 M4×0.7 通螺纹，CAD 以 Ø3.3 攻牙底孔表达；knee 外圈是 Ø4.4 通孔。定位杯、销孔和接触面不能统一套用宽松的一般公差。

打印方向影响强度和支撑需求，配合间隙应通过试片确定；参见 [Prusa：面向 3D 打印建模](https://help.prusa3d.com/article/modeling-with-3d-printing-in-mind_164135)。网格由系统 FreeCAD 的 `MeshPart.meshFromShape` 从实体生成，分件采用 0.06 mm 线性偏差；相关参数含义见 [FreeCAD 官方网格文档](https://github.com/FreeCAD/FreeCAD-documentation/blob/main/wiki/Mesh_FromPartShape.md)。

## 装配顺序

1. 检查所有打印件、试装轴承和嵌件。底壳保持开盖，先装 16 个 M3 热熔嵌件；不要在电池或电机已安装时加热嵌件。
2. 将两侧髋电机前静壳分别以 PCD50 的 6×M3×8 固定到髋安装板，再从壳外定位进 Ø64 窗口；每侧 4 套 M4×25 90°沉头螺栓穿过板和底壳承压座，外侧螺钉头不得高于安装板表面，壳内用金属垫圈、螺母固定。普通凸头会扫入旋转法兰，不可替换。机身内部保留拧紧工具空间。
3. CNC 两片保持分离：hip 片用 6×M3×16 接髋输出盘；knee 片用 4×M3×6 接膝背面静壳。确认分型面内螺钉头低于平面、定位杯正确就位、静壳与旋转颈部有间隙。
4. 每侧安装 2 个定位销，将两片在 Y=88 的分型面合拢；从膝侧用 4×M4×10 拧入 hip 外圈螺纹。此位置不用螺母。检查电机线束和接头方向后再最终锁紧。
5. 将 OB 固定到膝前静壳，将 OA 固定到膝输出盘。先核对电机零位与杆件相位；仅通电校零不能代替机械姿态检查。
6. 在 AC 两端及 BCW 的 B 点分别安装两只轴承；中间放 2 mm 钢内圈隔套。每个关节由内向外按“固定杆—2.5 mm 隔套—0.5 mm 内圈垫片—轴承对及中间隔套—0.5 mm 内圈垫片”排列。A/C 再加 3 mm 外隔套后装 25 mm 肩轴；B 直接用 20 mm 肩轴。内侧装 M5 螺母，检查无轴向松旷且转动自由。
7. 将 H6215 出线固定端装到 BCW 轮端，3 孔相位依据装配体；中央保留走线孔。再将轮圈用 6×M3×8 固定到输出端，装弹性轮胎。电机外壳与轮圈内壁保持间隙。
8. 安装电池托盘和绑带，再装电子托盘及最终电子件。线束应在静止结构上做应力释放，并为髋、膝全行程预留弯曲余量；避开连杆、轴承和轮胎。顶盖最后安装。
9. 断电、架空轮胎，先手动慢速通过允许行程，核查工具遗漏、卡滞、线缆拉扯、肩轴端部和螺钉头干涉。再做受控低载试装与逐步加载；加载后的间隙、紧固保持和永久变形必须重新检查。

## 已验证与未验证范围

- 每个定制件在导出时检查为单一有效实体；11 个分件 STL（含试片）回读为封闭网格，未检测到非流形、自相交或面朝向不一致，打印包围盒符合指定平台。
- `validation.json` 记录腿长 120～225 mm、间隔 5 mm 的 22 个姿态，Beta=0°。右腿所有打印/CNC 件及原始电机 STEP 的几何相交检查未发现超过 0.05 mm³ 的碰撞；左腿按镜像构造。离散姿态结果不证明连续行程或任意 Beta 均无碰撞。
- 原生 FCStd 表达式与独立运动学计算在 120、183.848、225 mm 三个腿长核对过位置。
- `joint_hardware_validation.json` 单独记录标称姿态下轴承、肩轴与钢隔套对定制件的包络检查。它不包含滚动体内部运动；大多数电机/壳体/CNC 螺钉、螺母、接头及线束未纳入完整装配干涉扫描。
- 仍需实物确定：电机接头空间与线束弯曲半径、CNC 定位配合、PETG 轴承座公差、紧固扭矩和防松方式、电子件包络、轮胎固定方式、壳体刚度、关节疲劳及物理限位。当前没有缓冲块或独立机械限位结构，软件行程范围不能替代机械限位。

## 重建

在工程根目录使用已安装的 FreeCAD Python 运行，先构建结构并完成验证，再导出装配 STL：

```sh
/Applications/FreeCAD.app/Contents/Resources/bin/python tools/build_printable_robot.py
/Applications/FreeCAD.app/Contents/Resources/bin/python tools/export_robot_assembly_stl.py
```

设计基线与部分输入位于 [design_parameters.json](design_parameters.json)。杆长、默认腿长、轴承孔径及定位杯直径由该文件读取；轴向堆叠和壳体尺寸目前在构建函数中定义，修改同名说明字段不会自动改变实体。主体逻辑位于 [build_printable_robot.py](../../tools/build_printable_robot.py)，壳体逻辑位于 [cad_chassis.py](../../tools/cad_chassis.py)。修改尺寸、姿态范围或硬件后必须重新导出并检查验证结果；已有 STL 不会随 FCStd 参数实时更新。

轴承名义尺寸6×19×6 mm核对自 [SKF官方626规格表](https://cdn.skfmediahub.skf.com/api/public/09468794f5d8f85a/pdf_preview_medium/09468794f5d8f85a_pdf_preview_medium.pdf)。封闭性、非流形、自相交与面朝向的独立STL回读结果见 [print_mesh_validation.json](print_mesh_validation.json)。

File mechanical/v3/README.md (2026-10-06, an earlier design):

# 双腿轮足机器人 V3：完整夹层与叉形关节

本版重新设计腿部厚度方向的承载结构：OB 使用两片从 O 连续延伸至 B 的完整侧板；A、C 为双耳叉，AC 的轴承舌位于叉口中间；B 的 CW 轴承舌位于两片 OB 之间。三处被动关节均由金属轴穿过两侧金属衬套支承。保留 130/35 mm 四杆中心距、真实电机接口和中空机身。

这是可制造和低载装配审查原型。打印网格及名义几何检查不能代替静强度、冲击、疲劳、PETG 蠕变或跳跃验证；本版没有额定载荷声明。髋—膝法兰为 6061-T6 CNC 件，其余定制刚性板壳为 PETG；轴、衬套、轴承、隔柱、挡圈、紧固件、电机和弹性轮胎使用金属或采购件。

## 文件与用途

| 文件 | 用途 |
|---|---|
| [wheel_leg_v3.FCStd](wheel_leg_v3.FCStd) | FreeCAD 原生装配、运动表达式及采购件几何参考 |
| [wheel_leg_assembly.step](wheel_leg_assembly.step) | 整机装配精确实体，包括真实电机模型 |
| [wheel_leg_structure.step](wheel_leg_structure.step) | 全部定制结构件，保留装配位置 |
| [wheel_leg_assembly.stl](wheel_leg_assembly.stl) | 单文件、多壳体装配展示模型，单位 mm |
| [print/](print/) | 生产用分件 STL，已按打印方向放平 |
| [step/](step/) / [cnc/](cnc/) | 精确分件 STEP；CNC 法兰需结合接口说明加工 |
| [parts.csv](parts.csv) / [part_manifest.json](part_manifest.json) | 分件名称、数量、尺寸和实体检查 |
| [INTERFACES.md](INTERFACES.md) | 真实电机孔系、来源及 CNC 法兰尺寸 |
| [metal_hardware/](metal_hardware/) | 两种光轴和 7 种隔套/铜套/垫片 STEP；按金属工艺制造 |
| [pin_specification.json](metal_hardware/pin_specification.json) / [spacer_specification.json](metal_hardware/spacer_specification.json) | 金属件数量、直径、长度、槽位及材料建议 |
| [curved_profile_validation.json](curved_profile_validation.json) | 未加入接口前的曲线轮廓及窗口边距记录 |
| [validation.json](validation.json) | 姿态抽样和相交检查记录 |
| [joint_hardware_validation.json](joint_hardware_validation.json) | 已建模关节硬件的名义几何检查 |
| [print_mesh_validation.json](print_mesh_validation.json) | 分件 STL 独立回读检查 |
| [assembly_stl_report.json](assembly_stl_report.json) | 装配 STL 内容、规模和包围尺寸 |

整机 STL 含 162 个对象、1,636,316 个三角面，约 78.0 MiB，标称姿态外包络约 232.67×443×283.81 mm，详见 [导出报告](assembly_stl_report.json)。STL 不保存材料、螺纹、关节或参数。切片器中使用 mm、100% 比例；整机 STL 含互相独立、接触和嵌套的零件，仅供查看装配，打印使用 `print/` 下分件。

## 预览

- [整机装配](previews/assembly.png)与[中空机身开盖](previews/open_chassis.png)。
- [右腿装配](previews/right_leg.png)、[轴向侧视](previews/right_leg_side.png)和[零件展开](previews/right_leg_exploded.png)。
- [夹层透视预览](previews/nested_joints_cutaway.png)隐藏 OB 外板并透明显示 A/C 外耳，用于检查中间活动舌；完整外板见整机装配。
- [A/B/C 名义剖面示意](previews/joint_sections.svg)与[O/A/B/C/W 机构图](previews/linkage_layout.svg)。剖面中的轴承和挡圈为安装包络示意，不是采购件加工图。

## 机构与完整夹层

坐标为 X 向前、Y 向外、Z 向上；下面 Y 值均为右腿局部装配坐标，左腿关于 Y=0 镜像。

- O 为髋/膝共轴中心；OB=AC=BW=130 mm，OA=BC=35 mm，C、B、W 共线沿用仿真定义。O 的髋输出带动膝静壳和 OB，膝输出带动 OA，AC 传递运动给 CW，W 为轮心。
- OB 由两片完整侧板构成：内板 Y=139～147，外板 Y=184～192；四根外 Ø10、内 Ø4.3、长 37 mm 的金属隔柱维持净间距。连接位置为相对 O 的 `(X,Z)=(31,12)、(31,−12)、(0,−66)、(0,−93)`。两板均从 O 延伸到 B，B 轴两端都落在完整 OB 板上。
- A 叉由 OA 内耳、O 中心桥和完整 OA 外耳组成。内耳 Y=150～158，外耳 Y=174～182，AC 端部轴承舌 Y=159～173，夹在中间；两侧各留 1 mm 钢内圈垫片空间。O 中心桥延伸至 Y=174，外耳通过真实转子 PCD27 的 6 个 M3 孔和内件共同固定。
- C 叉由 CW 主件的内耳、桥接区和可拆外叉板组成。C 内耳 Y=150～158，外叉板 Y=174～182；AC 的另一端轴承舌仍为 Y=159～173。两颗 M4 沉头螺钉把外叉板连接到 CW 的桥接区，位置相对 B 为 `(X,Z)=(±9,−20)`。
- B 为 CW 的中央轴承舌，厚 14 mm，Y=159～173，位于 OB 两片完整侧板之间。两侧用钢隔套和内圈垫片定位；通过长金属轴与 OB 双侧金属衬套支承。
- OB、CW 外轮廓由圆弧和三次 Bézier 曲线构成；OB 使用 3 个、CW 使用 4 个圆角窗口，窗口圆角 R2。孔系、桥区和轴承座附近保留材料；外形参考用户图片，尺寸由实际接口与装配层次决定。

| 关节 | 内侧支承 | 中央运动件 | 外侧支承 | 金属轴 |
|---|---|---|---|---|
| A | OA 内耳 150～158 | AC 轴承舌 159～173 | OA 外耳 174～182 | Ø6 g6 ×35，148.5～183.5 |
| C | CW 内耳 150～158 | AC 轴承舌 159～173 | CW 外叉板 174～182 | Ø6 g6 ×35，148.5～183.5 |
| B | OB 内板 139～147 | CW 轴承舌 159～173 | OB 外板 184～192 | Ø6 g6 ×56，137.5～193.5 |

A/C 中央舌的外侧仍位于两耳以内；B 中央舌位于两片完整 OB 以内。这一关系由上表中的厚度区间及端面决定，不依赖预览图颜色。

## 轴、衬套与挡圈

每关节使用 2 个 NSK 626ZZ1 轴承（6×19×6），或具有相同安装肩部尺寸的替代件，中间放 2 mm 钢内圈隔套。两耳各安装一只配 Ø6 轴、外 Ø8、长 8 mm 金属衬套；CAD 参考内孔 Ø6.05、打印座孔默认 Ø8.05，由 `bushing_bore` 参数控制；这是打印校准起点，不代表已获得名义过盈配合。按实购衬套和 PETG 试片确认轻压入、无松动且孔边不开裂。光轴穿过衬套和轴承，端部用两只轴用弹性挡圈防脱。轴不通过螺钉预紧夹住 PETG。

右腿的轴承均位于 Y=159～165 与 167～173，中间隔套 Y=165～167。A/C 两端各放 1 mm 钢内圈垫片（158～159、173～174）。B 内侧为 11 mm 隔套（147～158）加 1 mm 垫片，外侧为 1 mm 垫片加 10 mm 隔套（174～184）。直接接触轴承的 1 mm 内圈垫片及 2 mm 中间隔套均为外 Ø8.4、内 Ø6.2；B 的 11/10 mm 长隔套仍为外 Ø10，通过小垫片接触轴承。端部 0.2 mm 垫片外 Ø10，用于覆盖衬套端面，不直接压轴承。

安装肩部依据 [NSK 官方轴承目录 C060/C061 的 626ZZ1 条目](https://www.nsk.com/content/dam/nsk/common/catalogs/ctrgPdf/bearings/e1103c_partc.pdf)：内圈挡肩外径上限 db=8.5，外圈挡肩孔径下限 Db=16.5。选用 Ø8.4 内圈接触件；打印件两轴承之间的止肩通孔 Ø16.8，以避开 ZZ 防尘盖。不能把 Ø10 长隔套或普通大垫圈直接贴到轴承侧面，替代轴承也须复核这两个肩部边界。

| 光轴 | 数量 | 总长 | 挡圈槽坐标 | 槽宽 / 槽底直径 |
|---|---:|---:|---|---|
| A/C | 4 | 35 | Y=149～149.8、182.2～183 | 0.8 / Ø5.7 |
| B | 2 | 56 | Y=138～138.8、192.2～193 | 0.8 / Ø5.7 |

两种轴的槽位置相对各自轴端相同：第一槽距近端 0.5 mm，宽 0.8；远端槽距远端 0.5 mm。加工时两端挡边不得小于 0.5 mm，轴长和槽位公差不能使该尺寸低于原厂下限。槽与耳板之间各放 0.2 mm 金属端垫，A/C 位于 149.8～150、182～182.2，B 位于 138.8～139、192～192.2。槽宽 0.8 与名义挡圈厚 0.7 留有轴向装配间隙，最终游隙须按实际轴、槽、挡圈、轴承和垫片公差复核。

名义槽尺寸参考 [MISUMI 轴用 C 形挡圈 STWN6 官方尺寸表](https://us.c.misumi-ec.com/book/usa_2019_msm_fa/pdf/2629.pdf)：适用轴径 6，槽底 Ø5.7（0/−0.04），槽宽 0.8（+0.10/0），钢挡圈厚 0.7±0.04，安装后最大外包络 Ø12。不能用同号不锈钢系列或不同标准挡圈直接代换；订货时核对实际产品的材料、厚度、槽公差和最大安装外径。[光轴规格记录](metal_hardware/pin_specification.json) 与 STEP 配套使用；名义轴径 g6 为建议配合，选定轴承/衬套的实测配合和加工检验仍须确认。

这些轴需按图车削挡圈槽，或采购槽位匹配的可配置磨光轴；普通 Ø6/M5 肩螺钉不适用。加工后去毛刺，避免锐边刮坏衬套；槽根与材料热处理方式由加工方按选定轴材及载荷要求确认。轴承、衬套和轴的实际配合应先做样件检查，不能靠压碎 PETG 或强行过盈消除间隙。

## 电机、机身与运动参数

髋和膝各用一台 DM-J4310-2EC，每侧轮端用一台 DM-H6215。电机孔位来自用户提供的原始 STEP，螺纹深度结合原厂二维图；髋—膝两片式 CNC 法兰与机身安装位置沿用前版。外壳为 200×150×100 mm，中空，壁厚 3.2、底厚 4、可拆顶盖厚 4 mm；内部保留电池和电子托盘。

CW 轮端安装面改为 Y=173，H6215 整体比 V2 外移 9 mm。右轮中心 Y=199，两轮中心距 398 mm；H6215 输出面 Y=217.5。原仿真轮距 274 mm，本次没有修改 MuJoCo 模型，也没有重标质量、惯量或接触参数。

FreeCAD 中修改 `Parameters.LegLength` 可改变姿态。表达式由 130/35 mm 四杆关系计算装配位置；这不是 FreeCAD 原生 Assembly 约束求解器，没有实体接触求解或机械限位。已抽样检查腿长 120～225 mm、Beta=0°，范围和检查边界见下文及验证报告。修改杆长、摆角、轮距或硬件后需重新生成实体并检查，已有 STL 不会自动更新。

电池包暂按 110×50×35 mm 预留，电子托盘 188×46 mm；尚未根据最终采购件定版。侧向电机侵入机身空间，外壳整体内尺寸不能全部用作电池空间。

## 定制件与采购清单

| 分件名 | 整机数量 | 说明 |
|---|---:|---|
| chassis_lower_shell、chassis_lid、battery_tray、electronics_tray | 各 1 | 中空机身与两托盘 |
| hip_stator_mount | 2 | 髋静壳安装板 |
| OB_inner_full / OB_inner_full_left | 各 1 | 右/左完整内板 |
| OB_outer_full / OB_outer_full_left | 各 1 | 右/左完整外板 |
| OA_inner_hub、OA_outer_cheek | 各 2 | A 叉内件与完整外耳 |
| AC_bearing_link | 2 | 两端轴承舌的 AC 连杆 |
| CW_main_inner / CW_main_inner_left | 各 1 | 右/左 CW 主件，含 C 内耳和 B 中央舌 |
| CW_outer_fork / CW_outer_fork_left | 各 1 | 右/左可拆 C 外叉板 |
| wheel_rim | 2 | 带双侧防脱唇的轮圈 |
| bearing_fit_coupon | 1 | 626 轴承孔公差试片，不装入整机 |
| bushing_fit_coupon | 1 | Ø8 衬套座孔公差试片，不装入整机 |
| hip_rotor_cnc、knee_stator_cnc | 各 2 | 两片式 CNC 法兰，不能打印替代 |

合计为 13 类功能打印件、22 件，对应 17 个不同功能 STL；加两种试片共 19 个 STL。CNC 法兰 2 种、4 件。OB 和 CW 的对应左件使用 `_left` 文件，无后缀为右件；其余对称分件两侧翻面安装。最终文件及数量见 [parts.csv](parts.csv)，不可用任意翻面替代指定镜像件。

| 物料 | 规格 | 整机数量 | 用途 |
|---|---|---:|---|
| 髋/膝电机 | DM-J4310-2EC | 4 | 真实供应商模型 |
| 轮电机 | DM-H6215 | 2 | 真实供应商模型 |
| 关节轴承 | NSK 626ZZ1，6×19×6，或相同肩部尺寸替代 | 12 | 每 A/B/C 关节 2 个；db≤8.5/Db≥16.5 的安装边界 |
| A/C 光轴 | Ø6 g6 ×35，双挡圈槽 | 4 | 定制车槽或按图配置 |
| B 光轴 | Ø6 g6 ×56，双挡圈槽 | 2 | 定制车槽或按图配置 |
| 轴用挡圈 | 适配 Ø6，钢制，名义厚 0.7 | 12 | 每轴两端各一只 |
| 金属衬套 | 配 Ø6 轴，外 Ø8、长 8 | 12 | CAD 内孔 Ø6.05，实际配合复核 |
| 轴承中间隔套 | 钢，内 Ø6.2、外 Ø8.4、长 2 | 6 | 两个轴承内圈之间 |
| 轴承端垫 | 钢，内 Ø6.2、外 Ø8.4、厚 1 | 12 | 轴承对两端，只接触内圈 |
| B 内侧隔套 | 钢，内 Ø6.2、外 Ø10、长 11 | 2 | Y=147～158 |
| B 外侧隔套 | 钢，内 Ø6.2、外 Ø10、长 10 | 2 | Y=174～184 |
| 轴端垫 | 钢，内 Ø6.2、外 Ø10、厚 0.2 | 12 | 耳板与挡圈之间 |
| OB 金属隔柱 | 外 Ø10、内 Ø4.3、长 37 | 8 | 完整 OB 两板之间，每腿 4 根 |
| OB 两板连接 | M4×55 圆柱头、M4 六角螺母、内 Ø4.3/外 Ø9/厚 0.8 钢垫圈 | 8 套 | 每腿 4 套，配 37 mm 金属隔柱；螺母嵌于内板 |
| OA→膝转子 | M3×40 圆柱头 | 12 | 外耳沉孔底 177 到转子面 140 为 37，名义入牙 3 |
| C 外叉板连接 | M4×25，90°沉头，配 M4 六角螺母 | 4 套 | 每腿两颗，头不得高于叉板外面；螺母经 CW 内侧六角通道装入主件 |
| 弹性轮胎 | 外 Ø100、内 Ø86、宽 32 | 2 | 不用 PETG 实心胎 |
| 电池绑带 | 宽度不超过 10 | 2 | 配托盘槽孔 |

电机 M3 螺钉均按无垫圈计算名义入牙深度；加垫圈会改变啮合。前版 M3×20 的 OA 螺钉已不适用，本版按完整外耳的沉孔位置使用 M3×40。其余电机、CNC 和机身紧固件如下。电机孔未建真实牙型，需按实物有效牙深和螺钉公差确认不顶底。

| 位置 | 规格 | 整机数量 | 名义长度依据 |
|---|---|---:|---|
| 髋静壳→安装板 | M3×8 圆柱头 | 12 | 夹持 5，入牙 3，PCD50 |
| 膝前静壳→OB 内板 | M3×8 圆柱头 | 12 | 夹持 5，入牙 3，PCD50 |
| 髋输出→hip CNC | M3×16 圆柱头 | 12 | 夹持 11.5，入牙 4.5，PCD27 |
| 膝背壳→knee CNC | M3×6 圆柱头 | 8 | 夹持 2.5，入牙 3.5，PCD38 |
| H6215 固定端→CW | M3×8 圆柱头 | 6 | 夹持 5，入牙 3，PCD17.5 |
| H6215 输出→轮圈 | M3×8 圆柱头 | 12 | 夹持 4，入牙 4，PCD28 |
| 两片 CNC 连接 | M4×10 圆柱头 | 8 | 穿 knee 6，啮合 hip M4 牙 4；不用内侧螺母 |
| 两片 CNC 定位销 | Ø3、名义长 10 | 4 | 配合按实物及加工公差确认 |
| 髋板→底壳 | M4×25、90°沉头，配 M4 螺母、内侧钢垫圈 | 8 套 | 外侧齐平，不能改用凸头；总长包含沉头 |
| 顶盖→底壳 | M3×8 | 8 | 穿盖 4，入嵌件约 4 |
| 两托盘→底壳 | M3×6 | 8 | 穿耳/板 3，入嵌件约 3 |
| 底壳热熔嵌件 | M3，长度≤5，匹配 Ø4.2 座孔 | 16 | 具体孔径按嵌件厂商和 PETG 试样确认 |

CNC 两组 M3 螺钉的名义牙底余量仅 0.5 mm，应逐一核实头下长度、牙深、垫圈和倒角。M3 圆柱头需适配 Ø5.8/Ø6.2 沉孔。上述清单不包括最终电池、控制器、电子支柱、线束接头和护套。

## 打印与加工

打印基线为 220×220×250 mm 平台、0.4 mm 喷嘴、0.2 mm 层高、PETG、6 道外墙、8 层顶/底、40%～60% 填充。轴承座、衬套座、电机及隔柱连接区域建议局部 100% 填充。层间强度和实物配合须用打印样件验证；这些切片参数不构成承载保证。

1. 先打印两种公差试片。`bearing_fit_coupon` 从小 X 到大 X 的四孔为 Ø19.00、19.10、19.15、19.20；用实际 NSK 626ZZ1 试配，当前轴承孔参数 `bearing_bore` 默认 Ø19.15。`bushing_fit_coupon` 的四孔依次为 Ø8.00、8.05、8.10、8.15；用实购铜套选择可轻压入、装后无松动且孔边不开裂的孔径，`bushing_bore` 默认 Ø8.05。若衬套松动，修改孔径重印，不能把胶当作主要承载路径。不要整体缩放零件校正孔径，应修改对应参数后重建。
2. 采用导出 STL 的打印方向，在切片器内检查局部桥接、悬空台阶和支撑。多数平板以大面贴平台、轴孔轴线竖直；`OA_inner_hub` 与 `CW_main_inner`（含左件）有阶梯厚度和桥接结构，按 +90° 方向放置后仍有悬空部位，必须配置局部支撑，不能理解为全面贴床、无需支撑。两片式 OA/C 叉按独立零件打印，不能将装配姿态整体打印。
3. 轴承和衬套孔需保持同轴，不得在没有定位基准时随意手钻扩孔。装配前清理毛刺和支撑，验证金属件可以正常就位，孔边无开裂。
4. CNC 法兰按 [接口说明](INTERFACES.md) 与 STEP 审查加工。hip 外圈 M4×0.7 贯穿螺纹在 CAD 中用 Ø3.3 底孔表示，需攻牙；定位杯和销孔不得套用宽松的一般公差。
5. 光轴及精密隔套使用金属加工，禁止用打印轴、打印挡圈或打印隔套替代。槽位、衬套配合、轴承游隙及选定挡圈规格必须同时校核。

打印方向和壁厚设计参考 [Prusa 面向 3D 打印的建模说明](https://help.prusa3d.com/article/modeling-with-3d-printing-in-mind_164135)。轴承外形及安装肩部尺寸见前述 NSK 官方目录，不能仅按 6×19×6 外形尺寸选择替代件。

## 装配顺序

1. 先在空机壳安装 M3 热熔嵌件，试装电池/电子托盘。两侧髋安装板和 CNC 两片法兰按 [接口说明](INTERFACES.md) 分开安装到对应电机，再以定位销与外圈 M4 螺钉合拢。髋安装板外侧使用齐平沉头，避免扫入旋转法兰。
2. 把 OB 内板固定到膝静壳，OA 内件套到膝转子，检查定位杯和电机零位。OA 外件最终通过 6 个 M3×40 与转子固定，保持 A 叉两耳之间的夹层空间。
3. 在各耳安装 8 mm 金属衬套，在 AC 两端和 CW 的 B 舌各安装两只 626；内圈中间加入外 Ø8.4、长 2 mm 钢隔套。接合处仅清洁就位，不通过螺钉强行压缩轴承叠层。
4. 将 AC 的 A 轴承舌夹进 OA 两耳、C 轴承舌夹进 CW 的 C 两耳，两侧各加外 Ø8.4、厚 1 mm 钢内圈垫片。C 叉的两只 M4 螺母从内耳 Y=150 面沿六角通道推入至 Y=159～162.2 的承压位置，再从外侧装 M4×25 沉头。安装对应外耳/外叉板后，从一侧穿入 35 mm 光轴；轴端加入 0.2 mm 端垫并在两槽安装挡圈，确认挡圈全部进入槽内。
5. 将 CW 的 B 轴承舌放到 OB 内板之外，内侧依次放外 Ø10、长 11 mm 隔套和外 Ø8.4、厚 1 mm 垫片；外侧放外 Ø8.4、厚 1 mm 垫片和外 Ø10、长 10 mm 隔套。用四根 37 mm 金属隔柱合上完整 OB 外板，穿入 56 mm 光轴，在两端加入端垫和挡圈。连接板的螺钉夹紧隔柱，不用来调整轴承预载。
6. 逐关节检查转动顺畅、轴向游隙合理、轴不易脱出；用挡圈钳检查安装工具空间。挡圈不能卡在倒角、毛刺或槽外，端垫不能磨碰相邻运动件。
7. 将 H6215 出线固定端装到 CW 的轮端面 Y=173，保留中心出线孔，再安装轮圈和弹性轮胎。正反面三孔相位以真实装配为准；轮圈两侧防脱唇需配合有适当伸展性的弹性轮胎。
8. 安装电池、电子件和线束，留足关节全行程弯曲余量，线束固定在静止结构上做应力释放。顶盖最后安装。
9. 断电架空轮胎，手动慢速检查行程、线缆、挡圈、螺钉头和杆件间隙。之后再做受控低载试装及逐步加载，复查紧固、间隙、裂纹和永久变形。

## 验证范围与边界

- 系统 FreeCAD 1.1.3 检查每个定制件为单一有效实体。19 个分件 STL（17 功能件文件和 2 个试片）独立回读全部闭合，未检测到非流形、自相交或面朝向不一致；全部放平且适配 220×220×250 mm 打印平台。见 [零件清单](part_manifest.json) 与 [网格报告](print_mesh_validation.json)。切片支撑、裙边和实际打印误差仍需检查。
- 腿长 120～225 mm、每 5 mm 一个姿态，共 22 个姿态，Beta=0°。右腿打印/CNC 件、原始电机实体及已建模关节硬件的检查，未发现超过 0.05 mm³ 的相交；本版包含硬件与硬件之间的检查。相对固定零件对检查一次，相对运动零件对检查全部姿态，左腿按镜像构造。见 [几何检查](validation.json)。
- 原生 FCStd 结构和电机的位置表达式与独立运动学计算，在 120、183.848、225 mm 三个腿长核对位置一致。两侧共 128 个已建模硬件也在这三个姿态单独核对，未发现超过 0.001 mm 的位置误差；见 [原生硬件位置检查](native_hardware_placement_validation.json)。
- [硬件检查](joint_hardware_validation.json) 另列出 64 个右腿硬件对象，在标称姿态对制造件的检查无相交。包括光轴、挡圈、衬套、轴承、隔套、OB 拉杆、C 叉螺钉和 OA 转子螺钉的已建模部分。OA M3×40 仅建模外露的 37 mm 杆段及螺钉头，3 mm 入牙段省略；其啮合深度按名义长度计算。
- 未加入接口前的轮廓检查中，OB 窗口至外轮廓最小距离约 7.16 mm，CW 约 6.15 mm；OB 拉杆孔到窗口最小约 6.30 mm。见 [曲线轮廓报告](curved_profile_validation.json)。这些数字不是完整零件所有孔边的最小壁厚，也不构成强度验证。

上述几何检查不证明任意摆角、连续行程或动态载荷无碰撞；未建模的线缆、电机插头、紧固件公差和受载挠曲仍需实物检查。本版没有独立机械限位、缓冲块或强度定级。

## 重建

在工程根目录使用已安装的系统 FreeCAD Python，依次构建、导出装配 STL 并验证分件网格：

重建需保留工程上一级 `references/` 中用户提供的两款电机原始 STEP；文件名和路径见 [接口说明](INTERFACES.md)。压缩包包含构建脚本与生成结果，原始电机资料仍沿用工程内已有文件。

```sh
/Applications/FreeCAD.app/Contents/Resources/bin/python tools/build_nested_robot.py
/Applications/FreeCAD.app/Contents/Resources/bin/python tools/export_robot_assembly_stl.py --revision v3
/Applications/FreeCAD.app/Contents/Resources/bin/python tools/validate_print_meshes.py --revision v3
/Applications/FreeCAD.app/Contents/Resources/bin/python tools/render_nested_robot.py
```

V3 曲线控制点按 130/35 mm 中心距定义，构建脚本会拒绝直接改为其他杆长；修改杆长需同时修改并重新验证轮廓。

曲线轮廓由 [cad_v3_profiles.py](../../tools/cad_v3_profiles.py) 生成，装配由 [build_nested_robot.py](../../tools/build_nested_robot.py) 生成，通用导出和运动逻辑位于 [build_printable_robot.py](../../tools/build_printable_robot.py)。参数文件与实体尺寸的关系应结合脚本核对；已有 STL 不会随 FCStd 参数实时更新。

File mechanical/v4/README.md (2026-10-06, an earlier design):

# 双腿轮足机器人 V4：共层嵌套腿与两件电机法兰

本版先拆解用户参考图，再按真实电机接口复用其结构：OB 保留两片从 O 到 B 的完整侧板；CW 在 B 点位于两板之间；AC 两端分别嵌入 OA 和 CW 的双耳。腿部结构层从 V3 的53 mm压缩到 **33 mm**，通过外板和叉耳共用层面及轮廓避让实现，不把零件继续向外叠放。髋—膝连接改为带三定位销的小法兰与Ø57杯件，侧面四个螺钉锁紧。

保持 OB=AC=BW=130、OA=BC=35 mm，中空机身，每处关节改用两只更小的NSK686AZZ1轴承。OB、AC、CW及机身按PETG分件打印，OA内外两件与髋—膝两件法兰使用6061-T6 CNC；轴、铜套、隔套、挡圈和紧固件使用金属。当前为加工与低载装配审查原型，没有额定载荷、冲击或跳跃能力声明。

## 先拆参考图，再复用

[参考拆件分析](reference_breakdown.md)及[拆件示意图](previews/reference_breakdown.svg)区分图中可见结构、用户明确要求与本机新增制造分件。原图没有完整剖面和尺寸，不能从透视图断言所有隐藏件的厚度或孔系。

| 参考结构 | 本机复用后的零件 | 复用方式 |
|---|---|---|
| OB 两片完整上连杆 | `OB_inner_full`、`OB_outer_full` | 两板连续延伸到B，双侧支承B轴；外板O头开口避让曲柄 |
| 紫色 OA 曲柄 | `OA_inner_hub`、`OA_outer_cheek` | 拆成可加工的CNC内件和外耳，夹住AC的A端 |
| 红色 AC 连杆 | `AC_bearing_link` | 曲线细腰杆，两端保留12 mm双轴承舌 |
| 青色 CW 下连杆 | `CW_main_inner`、`CW_outer_fork` | B舌嵌入OB，C叉夹住AC；外叉采用偏置曲线支路 |
| 髋、膝之间的连接区 | `hip_rotor_cnc`、`knee_stator_cnc` | 依用户要求重做两件套筒，孔系来自真实4310资料 |
| 足盖和足端 | H6215安装部及`wheel_rim` | 替换为轮毂电机与弹性轮胎 |
| 髋横滚机构 | 不保留 | 采用现有双腿轮足运动学 |

OA与CW拆成主件/外耳是本机为加工、打印和轴承装入采用的制造分界，不声称原图隐藏位置也一定由同样数量的零件构成。

## 33 mm 共层结构

坐标为X向前、Y向外、Z向上，下表为右腿局部坐标，左腿关于Y=0镜像。O是髋/膝共轴中心，C、B、W共线。髋输出带动膝定子和OB，膝输出带动OA，AC将运动传给CW，W是轮心。

| 层面 | Y区间 | 作用 |
|---|---|---|
| OB完整内板 | 139～145 | 6 mm PETG板，固定在膝前定子 |
| CW的C内叉耳 | 146～152 | 6 mm PETG耳板，含6 mm铜套 |
| OA的A内叉耳 | 149～152 | 3 mm CNC耳，含3 mm铜套 |
| 内侧内圈垫片 | 152～153 | 1 mm钢垫片，只接触轴承内圈 |
| AC端舌、CW的B舌 | 153～165 | 12 mm，两只686AZZ1及2 mm中间隔套 |
| 外侧内圈垫片 | 165～166 | 1 mm钢垫片 |
| OA的A外叉耳 | 166～169 | 3 mm CNC耳，与OB外层部分共层 |
| OB外板、CW的C外叉 | **166～172** | 共用6 mm层面，实际轮廓避让彼此运动 |

完整结构层为Y139～172，即33 mm，比V3减少20 mm（约37.7%），不包括销端、挡圈和螺钉头外伸。OA整个组件从Y139.2延伸到170，轴向30.8 mm；V3为42.8 mm，本版缩短12 mm。OA外耳O中心盘局部厚5 mm、Y165～170，比3 mm的A端耳局部加厚；它向内嵌入1 mm，中心Ø12通孔减重，内桥结束于Y165。

这次减薄由两项共同实现：双轴承从626的14 mm叠层改为686AZZ1的12 mm叠层；OA铝件使用3 mm叉耳而非6～8 mm打印耳。OB外板O头采用圆弧开口避开A端扫掠，C外叉沿AC扫掠区域背侧布置曲线支路，连接螺钉相对B位于`(X,Z)=(-23,24)、(-23,46)`。旧A销端浅避空槽已删除，完整OB内板不靠该局部槽减薄。

OB、CW外形保留圆弧和三次Bézier曲线，镂空窗口采用圆角三角形。共同外层是实际零件相邻运动的层面，不能把两片有实体相交的板仅在显示中叠在一起。

| 关节 | 双侧支承 | 中央件 | Ø6轴长度及坐标 |
|---|---|---|---|
| A | OA内耳149～152 / 外耳166～169 | AC轴承舌153～165 | 23，Y147.5～170.5 |
| C | CW内耳146～152 / 外叉166～172 | AC轴承舌153～165 | 29，Y144.5～173.5 |
| B | OB内板139～145 / 外板166～172 | CW轴承舌153～165 | 36，Y137.5～173.5 |

OB两板之间净距21 mm，用四根外Ø10、内Ø4.3、长21的金属管保持，位置相对O为`(31,12)、(31,-12)、(0,-66)、(0,-93)`。B仅内侧使用7 mm长隔套，外侧内圈垫片直接邻接OB外板；不沿用V3的两侧长隔套。

## 两件电机法兰与真实定位销

每侧两件，整机4件。小法兰为Ø39颈部/Ø43插芯，杯件外径Ø57与4310壳体一致；Ø43插芯套入Ø43.05杯孔7 mm，侧面以4个M3×8连接，右侧相位15°/105°/195°/285°。膝后壳螺钉有轴向头部和工具通道，可在套合前安装。

原始二维图与STEP确认髋转子有3×Ø4(+0.02/+0.04)、PCD24.30定位孔。小法兰配置3根Ø4×9金属销，伸入电机3 mm、嵌入法兰6 mm，同时保留Ø35.05、深0.8的浅定位杯。转子与前定子同轴但端面相差1 mm，设计保留相对旋转避让。

加工尺寸、螺钉啮合、Ø2.5攻牙底孔及118°钻尖见[接口说明](INTERFACES.md)和[法兰专项检查](coupling_review.json)。STEP中的径向孔需要另攻M3×0.5，至少形成4.2 mm完整有效牙深；模型没有真实螺旋牙型。定位杯、插芯和销孔的实际公差应按电机、定位销、表面处理及加工能力确定，不能直接套用一般±0.1。

## 文件与用途

| 文件 | 用途 |
|---|---|
| [wheel_leg_v4.FCStd](wheel_leg_v4.FCStd) | 系统FreeCAD原生装配及运动表达式 |
| [wheel_leg_assembly.step](wheel_leg_assembly.step) | 整机精确实体，包括原始电机 |
| [wheel_leg_structure.step](wheel_leg_structure.step) | 定制结构件，保留装配位置 |
| [part_breakdown.FCStd](part_breakdown.FCStd) / [part_breakdown.step](part_breakdown.step) | 单零件分离审查布局，便于逐件查看，不是装配姿态 |
| [wheel_leg_assembly.stl](wheel_leg_assembly.stl) | 单文件、多壳体装配展示模型，单位mm |
| [print/](print/) / [step/](step/) | 按打印方向放平的分件STL / 精确分件STEP |
| [cnc/](cnc/) | 髋膝法兰及OA内外件STEP，配合接口与加工说明 |
| [parts.csv](parts.csv) / [part_manifest.json](part_manifest.json) | 文件、数量、尺寸、单实体检查 |
| [metal_hardware/](metal_hardware/) | 三种光轴和七种隔套、铜套、垫片STEP |
| [光轴规格](metal_hardware/pin_specification.json) / [隔套规格](metal_hardware/spacer_specification.json) | 金属件数量、直径、长度、槽位 |
| [转子定位销STEP](metal_hardware/dowel_D4_L9.step) / [定位销规格](metal_hardware/dowel_specification.json) | Ø4×9，整机6根，各伸入电机3、嵌入法兰6 |
| [design_parameters.json](design_parameters.json) | 运动尺寸、轴向层面与制造参数 |
| [validation.json](validation.json) | 完整装配姿态抽样与相交检查 |
| [print_mesh_validation.json](print_mesh_validation.json) | 分件STL独立回读检查 |
| [assembly_stl_report.json](assembly_stl_report.json) | 装配STL规模与外包络 |
| [native_hardware_placement_validation.json](native_hardware_placement_validation.json) | 原生FCStd硬件表达式位置核对 |

整机STL用于查看装配，不用于整体打印。STL不保留材料、螺纹、关节或参数；切片时用mm、100%比例，打印选择`print/`中的分件。装配STL包含194个对象、1,653,720个三角面，82,686,084字节（约78.86 MiB），标称姿态包围尺寸246.71×427×283.81 mm；STL二进制面数及文件字节数已与[导出报告](assembly_stl_report.json)核对。

预览：[零件分离布局](previews/part_breakdown.png)、[OA加工审查图](cnc/OA_crank_review.svg)、[33 mm共层剖面](previews/layout_shared_planes.svg)、[整机](previews/assembly.png)、[开盖机身](previews/open_chassis.png)、[右腿](previews/right_leg.png)、[轴向侧视](previews/right_leg_side.png)、[腿部展开](previews/right_leg_exploded.png)、[夹层查看](previews/nested_joints_cutaway.png)、[法兰两件](previews/coupling_parts.png)、[电机与法兰展开](previews/coupling_exploded.png)。夹层图隐藏OB外板并透明显示部分叉耳，完整零件仍在模型中。

## 轴承、铜套和轴向定位

每个A/B/C关节使用两只 **NSK686AZZ1，6×13×5**，或外形与防尘型安装肩部均相同的替代件。不是宽3.5的开式686A。右侧轴承位于Y153～158、160～165，中间为外Ø7.2、内Ø6.2、长2的钢隔套；两端各放同直径、厚1的内圈垫片。B内侧另放外Ø10、内Ø6.2、长7隔套，Y145～152；B外侧没有长隔套。

根据[NSK官方C060/C061表](https://www.nsk.com/content/dam/nsk/common/catalogs/ctrgPdf/bearings/e1103c_partc.pdf)，686AZZ1防尘型内圈挡肩外径上限7.4、外圈挡肩孔径下限11.7。采用Ø7.2内圈接触件与Ø11.8中央止肩避空孔，避免接触防尘盖；两只5.05深座孔之间保留1.9厚止肩。原始表及尺寸记录见[轴承选型证据](source/686AZZ1_selection_evidence.json)。旧Ø8.4内圈垫片不能直接沿用，Ø10长隔套须通过小垫片接触轴承。

同表单轴承基本额定值由626ZZ1的Cr2570/C0r885 N降为686AZZ1的Cr1190/C0r440 N。选择小轴承是紧凑性取舍，不代表同等承载替换；这些目录值不能直接换算为整机额定载荷，更不能直接乘轴承数量得出机器人承载能力。

A的CNC内外耳使用外Ø8、参考内Ø6.05、**长3**铜套；C和B仍使用**长6**铜套。PETG座孔默认Ø8.05供打印试片校准；OA铝件座孔名义Ø8.00，须单独确定机加工固定端配合，不能套用打印试片的孔径。两端各用外Ø10、内Ø6.2、厚0.2端垫和钢挡圈防脱；螺钉不通过压缩PETG或轴承叠层调整游隙。

| 轴 | 整机数量 | 长度 | 右腿挡圈槽Y区间 |
|---|---:|---:|---|
| A，建议Ø6 g6 | 2 | 23 | 148～148.8；169.2～170 |
| C，建议Ø6 g6 | 2 | 29 | 145～145.8；172.2～173 |
| B，建议Ø6 g6 | 2 | 36 | 138～138.8；172.2～173 |

三种轴均为槽底Ø5.7（0/−0.04）、槽宽0.8（+0.10/0）；两端槽外挡边至少0.5。钢STWN6/DIN471-6挡圈名义厚0.7，订货核对材料、厚度、槽公差和最大安装外径，参照[MISUMI官方表](https://us.c.misumi-ec.com/book/usa_2019_msm_fa/pdf/2629.pdf)。选用光轴须按槽位定制；普通带螺纹肩螺钉不能直接替代。

## 中空机身与轮端

机身外形200×150×100，壁厚3.2、底厚4、可拆顶盖厚4 mm；电池托盘暂按110×50×35包络，电子托盘188×46。侧向电机侵入机身，不能把整个壳体内腔当作连续可用空间；最终电池、控制器和线束尚需按实物布局。

CW的H6215固定安装面为**Y165**；右侧电机Y平移207，输出安装面Y209.5，轮中心Y191，两轮中心距**382 mm**。相对V3，轮电机各内移8 mm，轮距由398减到382。未修改原MuJoCo质量、惯量及接触标定，打印后的整机不能直接套用原简化模型的动力学参数。

FreeCAD中`Parameters.LegLength`由130/35四杆关系驱动姿态。它采用位置表达式，不是FreeCAD原生Assembly约束求解器，也没有实体接触求解或独立机械限位。改变杆长、摆角、孔位或硬件后须重新生成并检查；已有STL不会自动更新。

## 定制件与采购数量

| 定制分件 | 整机数量 |
|---|---:|
| `chassis_lower_shell`、`chassis_lid`、`battery_tray`、`electronics_tray` | 各1 |
| `hip_stator_mount`、`AC_bearing_link`、`wheel_rim` | 各2，PETG |
| `OA_inner_hub`、`OA_outer_cheek` | 各2，CNC铝件 |
| `OB_inner_full`、`OB_outer_full`、`CW_main_inner`、`CW_outer_fork`及各自`_left`镜像件 | 各1 |
| `bearing_fit_coupon`、`bushing_fit_coupon` | 各1，不装入整机 |
| `hip_rotor_cnc`、`knee_stator_cnc`及对应`_left` | 各1，CNC加工 |

实际导出为18件功能PETG件，对应15个功能STL，加两种试片共17个STL，已与`parts.csv`和`part_manifest.json`逐项核对。CNC为4类功能、8件实体：髋膝法兰4件加OA内外件4件，提供6个STEP文件（两法兰各左右文件，OA两件各一份）。OB/CW须按指定左右件打印；左杯不能用右杯翻面替代，OA按孔系方向翻面安装。

| 金属及采购物料 | 整机数量 | 规格 |
|---|---:|---|
| DM-J4310-2EC / DM-H6215 | 4 / 2 | 髋膝 / 轮端 |
| NSK686AZZ1轴承 | 12 | 6×13×5，每关节2个 |
| A轴 / C轴 / B轴 | 各2 | Ø6，长23 / 29 / 36，双挡圈槽 |
| 钢轴用挡圈 | 12 | STWN6/DIN471-6，名义厚0.7 |
| A铜套 | 4 | 外Ø8、参考内Ø6.05、长3 |
| B/C铜套 | 8 | 外Ø8、参考内Ø6.05、长6 |
| 轴承中间钢隔套 | 6 | 内Ø6.2、外Ø7.2、长2 |
| 轴承内圈钢端垫 | 12 | 内Ø6.2、外Ø7.2、厚1 |
| B内侧钢隔套 | 2 | 内Ø6.2、外Ø10、长7 |
| 轴端钢垫 | 12 | 内Ø6.2、外Ø10、厚0.2 |
| OB金属管 | 8 | 内Ø4.3、外Ø10、长21 |
| OB板连接套件 | 8套 | M4×35圆柱头、M4螺母、内Ø4.3/外Ø9/厚0.8钢垫圈 |
| C外叉连接套件 | 4套 | M3×25、90°沉头，M3螺母；总长包含沉头 |
| OA→膝转子 | 12 | M3×30圆柱头，夹27、入牙3 |
| 弹性轮胎 | 2 | 外Ø100、内Ø86、宽32；不使用PETG实心胎 |
| 电池绑带 | 2 | 宽度不超过10 |

OB的M4×35头下Y172.8、杆端Y137.8，在内板内侧有约1.2 mm杆端伸出，孔位避开膝定子包络；需按生成装配检查，不能擅自改成更长螺钉。C叉的螺母位于主件六角口袋Y153～155.4，从内侧通道装入，螺钉头不得高于Y172外面。

| 电机、法兰和机身紧固位置 | 整机数量 | 规格及名义啮合 |
|---|---:|---|
| 髋静壳→安装板 | 12 | M3×8，夹5、入牙3，PCD50 |
| **膝前定子→OB内板** | **12** | **M3×6，沉孔底Y142至定子Y139夹3，入牙3，PCD50** |
| 髋转子→小法兰 | 12 | M3×12，夹9、入牙3，PCD27 |
| 膝后定子→杯件 | 8 | M3×6，夹2.5、入牙3.5，PCD38 |
| 两法兰径向锁紧 | 8 | M3×8，夹3.8、入铝牙4.2 |
| 髋转子定位销 | 6 | Ø4×9，电机入3、法兰入6 |
| H6215固定端→CW | 6 | M3×8，沉孔底Y160至面Y165夹5、入牙3 |
| H6215输出→轮圈 | 12 | M3×8，夹4、入牙4，PCD28 |
| 髋板→底壳 | 8套 | M4×25、90°沉头，M4螺母与内侧钢垫圈 |
| 顶盖→底壳 | 8 | M3×8，穿盖4、入嵌件约4 |
| 两托盘→底壳 | 8 | M3×6，穿板3、入嵌件约3 |
| 底壳M3热熔嵌件 | 16 | 长≤5，选型匹配Ø4.2座孔并做PETG试片 |

上述M3圆柱头按无垫圈计算；添加垫圈或替换头型会改变入牙与外包络。尤其不能沿用V3的膝前定子M3×8：本版OB内板与沉孔已变薄，改用M3×6。实际螺纹有效深度、螺钉长度公差和头下圆角必须核对，禁止顶底。清单不含最终电池、控制器、线束和接头。

## 打印与加工

打印基线：220×220×250平台，0.4喷嘴，0.2层高，PETG；建议6道外墙、8层顶/底、40%～60%填充，轴承座、铜套座和连接孔附近局部100%填充。参数用于样件起步，不能替代层间强度和蠕变验证。

1. 先打印两种试片。轴承孔从小X到大X为13.00/13.10/13.15/13.20；铜套孔为8.00/8.05/8.10/8.15。用实购件选择轻压入、无松动、孔边不开裂的孔径；PETG默认`bearing_bore=13.15`、`bushing_bore=8.05`，OA的CNC铜套孔另按Ø8.00名义值指定实配。松动时修改孔径重印，不能整体缩放或把胶当主承载路径。
2. 使用STL导出方向，逐个检查局部支撑和桥接。`CW_main_inner`及对应左件有桥部和厚度台阶，仍需局部支撑；放平不代表全底面贴床。共层零件仍应分别打印后装配。
3. 清除毛刺和支撑，保持配对轴孔同轴；不要无定位基准地手钻扩孔。铜套、轴承与轴应先做样件配合，不靠压碎PETG消隙。
4. 髋膝法兰和OA铝件按[INTERFACES](INTERFACES.md)及各自STEP加工；Ø2.5径向底孔须攻M3×0.5，定位孔和套合面按实物指定配合。
5. 轴、铜套、精密隔套和挡圈使用金属件，槽位及端挡边需检验。切片支撑、打印收缩与加工公差均不由CAD网格验证覆盖。

打印方向与厚度处理参考[Prusa建模说明](https://help.prusa3d.com/article/modeling-with-3d-printing-in-mind_164135)。

## 装配顺序

1. 在空机壳安装M3热熔嵌件并试装托盘。用齐平沉头把髋安装板装到机壳，按接口说明将两法兰分别固定髋转子和膝后定子，再套合并装四个径向M3×8。
2. 用M3×6将OB内板固定膝前定子；OA内件套在膝转子，核对浅杯与零位。OA外耳最终用6个M3×30穿过27 mm夹持段固定，不能先夹死活动舌。
3. 在A的3 mm铝耳、C/B的6 mm打印耳分别装对应长度铜套；AC两端和CW的B舌各装两只686AZZ1，中间放2 mm内圈隔套。
4. 将AC的A、C端舌分别放入OA与CW叉口，两端各放1 mm内圈垫片，装对应外耳。C主件由内侧通道装M3螺母，再装两颗M3×25沉头；A穿入23 mm轴、C穿入29 mm轴，端部加0.2垫片和挡圈。
5. B内侧按OB内板→7 mm隔套→1 mm内圈垫片→CW轴承舌布置；外侧为1 mm内圈垫片→OB外板。放入四根21 mm金属管，合上OB完整外板，用M4×35套件夹紧金属管，穿入36 mm轴并装端垫、挡圈。
6. 确认三处关节转动顺畅、轴向间隙合理，挡圈完全入槽。共同外层的OA外耳、OB外板和C叉应相邻避让；不能用垫片向外叠厚来掩盖零件或零位错误。
7. 将H6215固定端装到CW的Y165面，保留中央出线孔，再装轮圈和弹性轮胎；两侧防脱唇应配可伸展轮胎。
8. 布置电池、电子件和线束，应力释放固定在所属静止件上，保留关节行程所需弯曲余量；最后装顶盖。
9. 断电、架空轮胎，慢速手动检查全行程、销端、挡圈、螺钉头和线束。再做受控低载台架试验，逐步加载后复查松动、裂纹、永久变形与间隙。

## 验证范围与边界

以下结果来自本版33 mm、686AZZ1与OA CNC最终实体：

- [分件清单](part_manifest.json)：23个不同定制文件几何（含两试片），各为单一有效实体；其中6个CNC文件对应8件铝件，15个功能PETG文件对应18件实物。
- [网格回读检查](print_mesh_validation.json)：17个打印STL全部闭合，未检测到非流形、自相交或法向不一致；全部放平并适配220×220×250打印平台。局部支撑、裙边和实物误差仍需切片检查。
- [完整装配检查](validation.json)：腿长120～225、每5 mm取样，共22姿态，Beta=0°，未发现超过0.05 mm³的相交；包含右腿结构、原始电机和已建模五金，也检查五金之间相交。相对固定零件对检查一次，相对运动零件对检查所有取样姿态；左侧由镜像构造。
- [原生硬件位置](native_hardware_placement_validation.json)：两侧共160个硬件对象，在120、183.8477631085、225 mm三个腿长与独立运动学位置比较，无超过0.001 mm的误差。
- [标称姿态硬件检查](joint_hardware_validation.json)：80个右腿硬件对象与制造件检查无相交。几何包括实际选择的光轴、挡圈、铜套、轴承、隔套和已建模螺钉；啮入电机或攻牙孔的杆段按报告说明省略，采购长度按本清单而非显示长度。
- [法兰局部检查](coupling_review.json)：包括两颗原始电机与完整定位销，无超过0.001 mm³相交；所建工具探针通道无相交。孔间几何间隔见接口说明。

[装配STL导出报告](assembly_stl_report.json)已生成，包含194个对象；该文件仅用于查看整机，打印使用17个分件STL。

相交检查仅覆盖报告列出的实体及离散姿态。它不证明连续行程、任意摆角或受载挠曲无碰撞；未建模紧固件、线缆、接头、打印误差和动态变形需实物核对。模型未设置独立机械限位或缓冲件，没有静强度、疲劳、冲击和跳跃定级。清单中的名义实体质量不是切片耗材质量，也没有作为重新标定的整机惯量。

## 重建

在工程根目录使用系统FreeCAD Python；原始两款电机STEP应保留在工程上一级`references/`，路径见接口说明。生成STL不会随FCStd参数自动同步，修改后须重新导出。

```sh
/Applications/FreeCAD.app/Contents/Resources/bin/python tools/build_compact_robot.py
/Applications/FreeCAD.app/Contents/Resources/bin/python tools/export_robot_assembly_stl.py --revision v4
/Applications/FreeCAD.app/Contents/Resources/bin/python tools/validate_print_meshes.py --revision v4
/Applications/FreeCAD.app/Contents/Resources/bin/python tools/render_compact_robot.py
```

几何来源为[cad_v4_leg.py](../../tools/cad_v4_leg.py)和[cad_v4_coupling.py](../../tools/cad_v4_coupling.py)，主构建为[build_compact_robot.py](../../tools/build_compact_robot.py)。曲线及部分通用函数仍依赖`cad_v3_profiles.py`、`build_nested_robot.py`、`build_reference_robot.py`、`build_printable_robot.py`与`cad_chassis.py`；预览依赖`render_nested_robot.py`。本版曲线和开口为130/35中心距设计，改变杆长需同步修改轮廓、孔位和扫掠避让后重新验证。

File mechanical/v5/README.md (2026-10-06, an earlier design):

# V5 双腿轮足：完整外框包裹的一体叉连杆

本版按参考图重新拆件：每腿的 **OB 是内外两片完整框板，OA 放在两片 OB 之间；OA 与 CW 各自加工成一体叉，AC 两端嵌入叉口，CW 的 B 轴承舌嵌入 OB 两侧支承**。双剪由金属轴两端的实际支承形成。每个 A/B/C 关节仅使用一颗 626 轴承，双剪不要求两颗轴承。

关键承载件采用 6061-T6 CNC；中空机身的上舱、顶盖、托盘及相机支架采用 PETG。髋与膝均为用户确认的 **24 V、V1.1 驱动版本 J4310**，轮端为 H6215，删除参考图的髋横滚与普通足端。当前整机预算约5.58 kg。按CAD分布质量，标称姿态和120 mm低蹲的每侧膝重力需求分别约1.96、2.46 N·m；平地低速运行具备初算可行性，**跳跃能力尚不能确认**。完整条件与限制见 [MOTOR_LOAD.md](MOTOR_LOAD.md)。

## 从参考图到实际分件

先看 [参考图逐件拆分](reference_breakdown.md) 与 [轴向层次图](previews/reference_breakdown.svg)。五个主要连杆 CNC 件如下；轴、轴承、铜套和保持片另计。

| 每腿实体 | 复用的结构关系 | V5 的实际做法 |
|---|---|---|
| `OB_inner_full` | 完整 O→B 内板 | 电机接口、B 内支承和四个框间连接柱一体加工 |
| `OB_outer_full` | 完整 O→B 外板 | 连续覆盖 OA；B 外支承向内伸入，四颗螺钉与内板合框 |
| `OA_one_piece` | O→A 紫色曲柄 | 转子座与 A 两个耳合为一个 CNC 件，嵌在 OB 里面 |
| `AC_bearing_link` | A→C 红色连杆 | 连续曲线杆身；两端各一颗轴承及独立外圈保持片 |
| `CW_one_piece` | C、B、W 同一刚体 | C 双耳、背桥、B 轴承舌与轮端连接一体加工，取消外加 C 帽与长螺钉柱 |

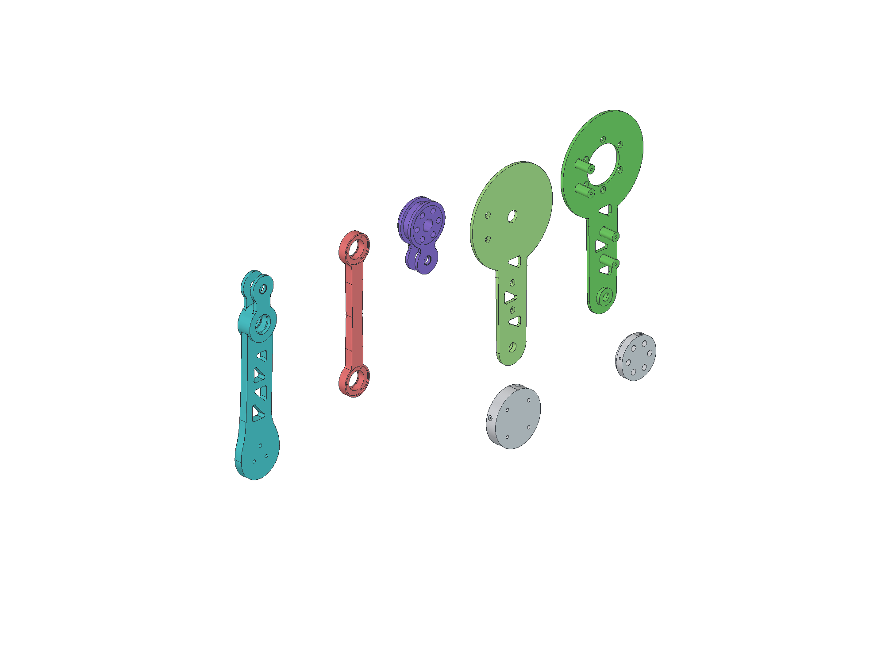
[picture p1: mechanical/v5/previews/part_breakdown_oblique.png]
V5实际CNC零件分离图


图中上排从左到右为CW、AC、OA、OB外板、OB内板；下排为两件法兰。这是独立零件审查排布，不是真实装配位置。可打开 [分件FreeCAD](part_breakdown.FCStd)、[分件STEP](part_breakdown.step)；对照 [右腿爆炸图](previews/right_leg_exploded.png) 和 [拆盖查看OA内嵌](previews/OA_inside_OB.png)。

130/35 mm 是关节中心距：OB=AC=BW=130，OA=BC=35。外形采用连续圆弧、过渡曲线和保留承载边的开窗；零件分界不根据图片颜色臆造。参考图被遮挡的轴向保持件由本版明确设计，其尺寸不宣称来自原图。

## 更薄的轴向结构

腿部承载件总宽 **22 mm**，以膝前定子面 S=132.1 为基准：OB 内板 S..S+3，外板 S+19..S+22；OA/CW 两耳分别为 S+3.5..6.5 和 S+15.5..18.5。AC 与 B 中央舌为 S+7..15。OA 外耳位于 OB 外盖内侧，采用真正的内嵌结构，不靠几片零件在外侧继续叠厚。

三处被动轴均为 Ø6 钢轴、两侧铜套支承，单颗 NSK626ZZ1（6×19×6）通过肩部和螺钉保持片固定外圈。钢轴两端使用 M2 内螺纹和超薄头保持件防脱，轴向留明确游隙；不得将薄保持螺钉当作主要剪切承载轴。完整层面、轴孔和铜套尺寸见 [INTERFACES.md](INTERFACES.md)。

髋转子与膝定子间保留两件 CNC 法兰，轴向总跨度 **14.9 mm**：带三根真实 Ø4 定位销的转子法兰，嵌入外 Ø57 的膝定子杯内，套合长7；四颗径向螺钉穿过杯壁进入插芯螺纹。使用 NBK 小头低头螺钉缩短连接，不能直接换成普通高头。详见 [法兰剖面与验证](coupling_review.md)。

轮端固定面 Y147.1，右 H6215 平移 Y189.1，输出面 Y191.6；轮心 Y173.1、轮距 **346.2 mm**。这些值与22 mm连杆和新膝电机位置配套，不能混用 V4 的轮端位置。

## 中空机身及设备布置

机身外廓 **200×150×135 mm**（Z−50..85）。五片金属下壳到 Z47，PETG 上舱到 Z82，可拆顶盖到 Z85；PETG 电子托板上表面 Z33。五片下壳实际铣兜减重后共 **793.044 g**，同一基型关闭减重兜为964.016 g，减少170.972 g。此数只包括五片金属下壳。

完整 Jetson Orin Nano 主机按最大103.2×90.7×35.86 mm包络布置，接口朝+X；D435嵌入前上面板，正面与X100齐平。电池暂按400 g、110×50×35 mm，IMU暂按20 g、25×30×12 mm。四个设备实体是尺寸占位，不是原厂完整CAD或最终安装支架。

D435 后部两颗 M3×5 通过3 mm支架名义入牙2 mm，低于原厂最大3 mm；相机支架通过机身四孔Y±50、Z56/72连接。相机/Jetson来源、线头空间和未定设备假设见 [payload_interfaces.json](payload_interfaces.json)。具体壳体分件、通风孔、金属攻牙和装配顺序见 [CHASSIS.md](CHASSIS.md)。

## 文件与工艺

- [整机预览](previews/assembly.png)、[开舱设备布局](previews/electronics_layout.png)、[关节剖面](previews/joint_sections.png)：用于先检查结构和装配层次。
- [原生 FreeCAD 装配](wheel_leg_v5.FCStd)：含位置表达式、原始电机及设备占位，适合分组查看和修改参数。
- [完整装配 STEP](wheel_leg_assembly.step) 与 [结构装配 STEP](wheel_leg_structure.step)：供交换和检查；供应商按单件工艺文件制造。
- [整机装配 STL](wheel_leg_assembly.stl)：已保留装配位置，含242个对象、1,723,230个三角面，约86.16 MB；外廓235.17×391.20×318.81 mm。用于整机多壳查看，不作为一体打印文件；[导出回读报告](assembly_stl_report.json)。
- [零件清单](parts.csv)、[零件几何/工艺清单](part_manifest.json)、[设计参数](design_parameters.json)：文件名、数量、材料和层面的依据。
- `cnc/`：金属主体单件 STEP。左右件按文件分开，尤其杯件不能随意翻面互换。
- `print/`：PETG 附件的独立 STL，已放置到打印平台。默认220×220×250 mm、0.4 mm喷嘴、0.2 mm层高。上舱相机窗口、侧通风长槽与悬挑螺母柱需局部支撑；模型闭合检查不等于免支撑。需要按实际打印机复核孔配合、方向并清理支撑。
- `stl/`：结构单件的查看网格。CNC件的STL不是金属加工图，也不表示允许将其改为PETG承载件。
- [自制轴/保持件规格](metal_hardware/specification.json) 与 [法兰销、螺钉规格](coupling_fasteners.json)：包括加工小五金和标准件需求；[Ø4×9定位销STEP](metal_hardware/dowel_D4_L9.step)为名义圆柱，全机6枚，原料截短、端部倒角和固定/可拆端配合应在加工图中注明。

本版主制造清单为 **22个CNC STEP、23件金属主体；5个PETG STL、5件附件**，加工小五金和采购件另列。装配体 STL 已输出，包含原始电机、已建五金、轮胎和四个设备包络；打印使用独立PETG STL。真实螺纹在加工STEP中主要以底孔表示，必须依接口说明攻牙；不能将底孔径当作成品螺纹。

## 装配要点

1. 先安装 AC 两端和 CW 的 B 轴承；装外圈保持片及三颗 M2 螺钉，再进入叉口。先检查轴承可转动和保持片只接触外圈。
2. **在 OB 框外**装好 OA–AC 的 A 轴双端保持件，再完成 AC–CW 的 C 轴连接。OA 装进 OB 后，A 内側 T4 工具会被完整内板挡住。
3. 髋板、电机两件法兰及膝电机按专项说明装好；将 OB 内板固定到膝前定子，把预装子机构插入内框，装 OA 六颗 M3×16 转子螺钉。
4. 对齐 B 轴与 OB 两侧铜套支承，装外盖及四颗 M3×8；完成 B 双端保持。OB 外盖的 Ø12 中心孔不能用于穿过 PCD27 安装全部 OA 螺钉，维修 OA 时应拆盖。
5. 安装 H6215、轮圈和轮胎；完成机身、电子件、相机及线束，最后固定上舱与顶盖。全程检查轴端游隙、轴承转动、螺钉露牙和电机接线空间。

## 最终验证与载荷状态

- [完整几何检查](validation.json)：腿长120..225 mm、每5 mm一档，共22姿态，β=0；包含已建硬件间检查，无超过0.05 mm³相交。所有导出主体为有效实体，网格闭合。
- [原生硬件随动检查](native_hardware_placement_validation.json)：202个硬件对象在120、183.847763、225 mm三个姿态与计算位置一致，0.001 mm位置阈值内无错误。
- [PETG打印网格检查](print_mesh_validation.json)：5个STL全部通过闭合、非流形、自相交、法向和220×220×250 mm平台检查。
- [质量预算](mass_budget.json)：整机名义 **5.580 kg**，安装/打印/轮胎等不确定性范围约 **5.380..5.880 kg**；该范围不是统计置信区间。包含完整Jetson、D435、400 g电池、20 g IMU占位及0.2 kg安装余量；PETG按CAD实心体积估算，最终须称量。

[电机负载与跳跃筛查](MOTOR_LOAD.md)已分别列出集中质量近似与CAD分布质量结果；后者计入下肢重心和轮端非簧载质量。低蹲重力需求约2.46 N·m尚有有限额定余量，但未计平衡控制峰值、冲击及热负载；本次J4310按已确认的24 V、V1.1驱动版本分析，不能用3/7 N·m额定/峰值数值直接保证跳跃。离散β=0检查未覆盖任意机身倾角、连续路径最小间隙、弹性变形、线缆扫掠或未建螺钉；几何无相交不证明跳跃冲击、疲劳或螺纹强度满足要求。

## 重建

在工程根目录使用系统 FreeCAD Python：

```sh
/Applications/FreeCAD.app/Contents/Resources/bin/python tools/build_enclosed_robot.py
/Applications/FreeCAD.app/Contents/Resources/bin/python tools/render_enclosed_robot.py
/Applications/FreeCAD.app/Contents/Resources/bin/python tools/export_robot_assembly_stl.py --revision v5
/Applications/FreeCAD.app/Contents/Resources/bin/python tools/validate_print_meshes.py --revision v5
```

`--integration-check` 仅运行120、183.847763和225 mm三个姿态用于快速整合，不可替代不带该参数的最终完整检查。原始电机参考文件必须保留在项目上层 `references/` 中。V5输出独立放在本目录，V4归档保持不变。

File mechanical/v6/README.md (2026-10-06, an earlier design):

# V6 双腿轮足：包覆式 OB 与曲面中空机身

本版对应用户确认的 **24 V、V1.1 驱动 J4310** 髋/膝电机，轮端为 H6215。关键承载件采用6061-T6铝合金CNC；整高曲面外壳、托盘及相机支架采用PETG。V5文件保留。

## 腿部修改

- **OB=AC=130、BW=105、OA=BC=45 mm**。BW由130缩短19.2%，OA/BC由35加长28.6%；名义髋轮距180，几何检查范围100～215。
- O端外径由旧大圆盘缩到 **Ø57**，与真实膝电机定子一致。先装内承载臂，再将OA穿过中央开口连接转子，最后套入带连续侧壁、定位台阶和背面口袋的OB外壳。
- A/C的轴承舌嵌进OA/CW两叉耳之间，B轴承舌嵌进OB两支承之间；每处一颗626轴承，金属轴两端受支撑。CW的C、B、W保持一个CNC刚体。
- 主轴向结构宽 **23 mm**；外侧限位销头局部达到24.7 mm。V5主结构为22 mm，本版增加1 mm以实现Ø57头部真实包覆、必要间隙和独立止挡，不能称作全局又减薄1 mm。
- 外侧O圆孔有同轴台阶，OA轮毂径向单边留0.20、轴向留0.40；它是间隙保护/防脱结构，不是新增承重滑动轴承。另设R23弧槽和可拆Ø4钢肩销限制角度。
- 两件髋转子—膝定子嵌套法兰沿用已核对的14.9 mm轴向设计；定位销、径向锁紧孔与原始电机孔系保留。

先看 [参考图拆件](reference_breakdown.md)、[接口与公差说明](INTERFACES.md) 和 [制造/装配顺序](leg_construction_notes.md)。原图隐藏尺寸未被当作可测数据；本版尺寸来自真实电机、参数设计及几何检查。

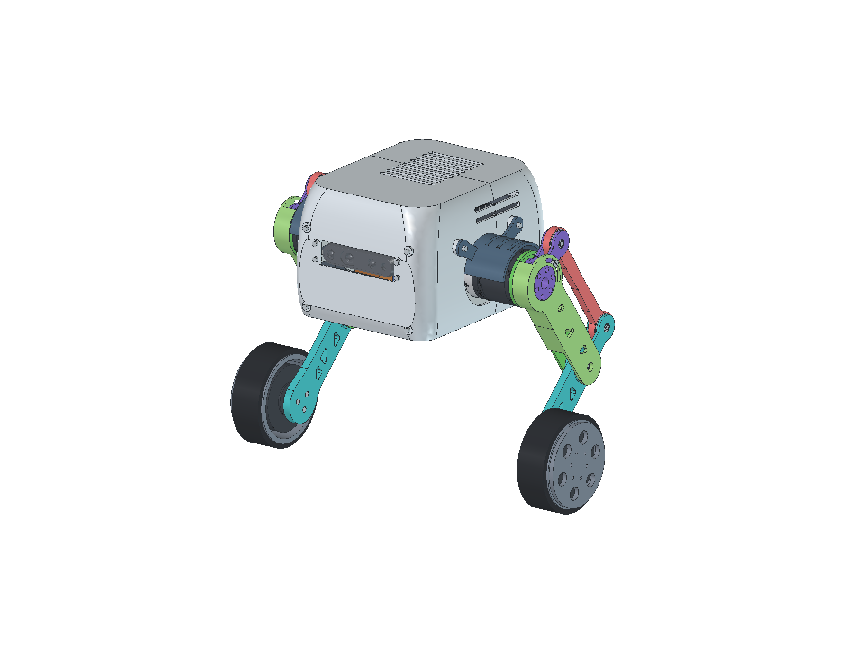
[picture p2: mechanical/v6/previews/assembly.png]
整机


## 设备与机壳

机身采用重新布置的金属承力内框与整高连续曲面中空外壳，取消叠在原方壳上方的独立上舱。左右弧形肩部延伸到膝电机区域；底部及运动侧留出连杆摆动和维护空间。外罩不承担腿部冲击载荷。

**Jetson和D435均安装在机壳内部**。D435位于连续前面板中，中心Z19、正面X100，光学窗口保持开放；Jetson位于机身内部中后方，保留原底座、风扇和散热器，并设置独立托盘与可拆固定件；电池留在低位。设备布局与实际机壳尺寸见 [CHASSIS.md](CHASSIS.md)。

- Jetson使用[NVIDIA官方完整开发套件STEP](https://developer.nvidia.com/downloads/assets/embedded/secure/jetson/orin_nano/docs/jetson_orin_nano_devkit_3d_step_model.zip/)，版本20230320。保留1393个实体，包含P3768载板、P3767模块包络、风扇、散热器和底座；仅排除辅助开放曲面，未缩放实体。原件和校验记录在 `source/jetson/`。
- D435的[官方CAD包](https://dev.realsenseai.com/docs/cad-files/)提供SolidWorks格式，原件保存在 `source/d435/`。FreeCAD装配和整机STL纳入[RealSense官方ROS详细网格](https://github.com/realsenseai/realsense-ros/blob/ros2-master/realsense2_description/meshes/d435.dae)，不是原来的方盒视觉占位。网格保留原拓扑，未补洞或缩放外形。
- **D435版本差异已明确处理**：2018官方ROS模型深25.05 mm，2025尺寸图为26.05 mm。本次可视装配按旧网格设后安装面X74.95，支架面X73.95，中间加可拆1 mm金属垫片，两颗M3×6名义入牙2 mm。26.05 mm实物去掉垫片并改M3×5。下单前按实物确认版本与后安装面。
- 电池仍按用户指定400 g、假定110×50×35 mm矩形；IMU暂按20 g、25×30×12 mm。二者明确标为包络，不冒充原厂模型。

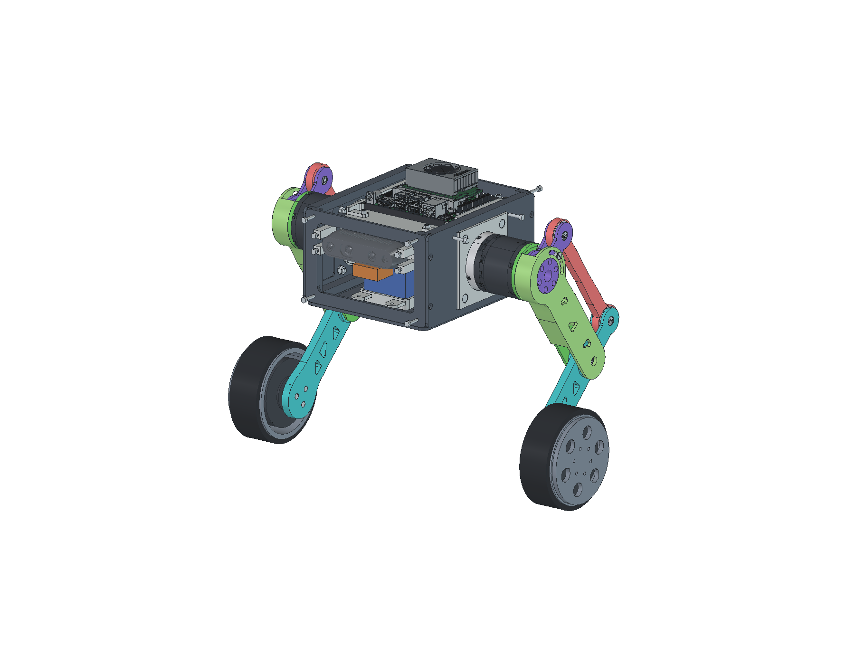
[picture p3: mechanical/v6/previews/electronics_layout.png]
移除外壳后的内部布局


## 文件用途

| 文件 | 用途 |
|---|---|
| [wheel_leg_v6.FCStd](wheel_leg_v6.FCStd) | 原生装配，含位置表达式、原厂电机、Jetson实体、D435官方网格和设备安装件 |
| [wheel_leg_assembly.stl](wheel_leg_assembly.stl) | 保持装配位置的整机多壳查看模型，包含真实设备模型；不用于整机一体打印 |
| [wheel_leg_structure.step](wheel_leg_structure.step) | 制造结构装配，不含采购电子设备 |
| [wheel_leg_assembly.step](wheel_leg_assembly.step) | BRep交换装配；Jetson是真实实体，D435在此STEP中为有明确标注的安装检查包络；相机原厂SLDPRT另附 |
| [part_breakdown.FCStd](part_breakdown.FCStd) / [STEP](part_breakdown.step) | 五类腿部主体及两件式法兰，共七个主件的独立查看排布 |
| [leg_exploded_review.FCStd](leg_exploded_review.FCStd) | 右腿爆炸查看，不是装配位置 |
| [parts.csv](parts.csv) / [part_manifest.json](part_manifest.json) | 零件、数量、材料和网格状态 |
| `cnc/*.step` | 承重金属主体，左右件分别输出 |
| `stl/*.stl` | CNC零件的参考网格，用于查看或试配；承重成品按金属工艺加工 |
| `print/*.stl` | PETG独立打印件，按220×220×250 mm平台检查 |
| `metal_hardware/` | 金属轴、衬套、保持片、限位销和调节垫片参考形状/规格 |

PETG默认0.4 mm喷嘴、0.2 mm层高。曲面罩、螺母穴和长通风槽可能需要支撑；实际切片、孔配合和材料耐温需按打印机确认。CNC螺纹多以底孔表达，必须按接口说明攻牙，不能把底孔当成最终通孔。名义CAD不替代带公差、牙深及表面处理要求的加工工程图。

## 已做的检查与适用边界

[O接口独立审查](O_interface_independent_review.json)检查原电机孔系、工具路径、螺纹芯通道、套壳过程及角度止挡。**只能按180 mm名义姿态执行所给轴向装壳路径**；100 mm深蹲姿态中途会擦碰，禁止强行套入。

理想止挡首次接触角为−135.747°/−47.753°，相应髋轮距约217.90/97.83 mm。接触时AC到壳仍留0.858/0.443 mm，止挡先于主体碰撞。正常控制限位须保持在100～215 mm工作范围内；止挡不用于反复冲击制动。

整机最终几何、打印网格、质量和电机负载见：

- [整机运动相交检查](validation.json)、[硬件随动](native_hardware_placement_validation.json)、[机壳检查](chassis_review.json)。
- [独立PETG网格检查](print_mesh_validation.json)、[整机STL导出回读](assembly_stl_report.json)。
- [质量预算](MASS.md)、[24V电机负载及跳跃筛查](MOTOR_LOAD.md)。

最终质量预算约 **5.642 kg**。名义180 mm姿态每膝重力负载约 **1.641 N·m**，采样最大约 **2.259 N·m**；低速平地力矩筛查可行。100 mm落差、50 mm缓冲的膝负载粗筛约 **6.866 N·m**，已接近7 N·m峰值，因此不能把静态余量视为跳跃/落地通过。

本版运动检查是固定β=0的离散姿态检查，不覆盖任意机身倾角、连续运动最小间隙、线缆扫掠或弹性变形。电机负载计算不等于跳跃能力证明；峰值转矩不能与空载最高转速同时使用。未沿用V5的旧OB截面抗压结果，新包覆壳的跳跃冲击、疲劳、螺纹承压和热性能尚待验证。

## 重建

在本工程根目录，使用系统FreeCAD Python：

```sh
/Applications/FreeCAD.app/Contents/Resources/bin/python tools/build_sleeved_robot.py
/Applications/FreeCAD.app/Contents/Resources/bin/python tools/render_sleeved_robot.py
/Applications/FreeCAD.app/Contents/Resources/bin/python tools/analyze_v6_motor_load.py
/Applications/FreeCAD.app/Contents/Resources/bin/python tools/export_robot_assembly_stl.py --revision v6
/Applications/FreeCAD.app/Contents/Resources/bin/python tools/orient_v6_prints.py
/Applications/FreeCAD.app/Contents/Resources/bin/python tools/validate_print_meshes.py --revision v6
python3 tools/package_sleeved_robot.py
```

原始电机STEP仍使用工程旁的 `../references/DM-J4310-2EC` 与 `../references/DM-H6215`。官方电子设备源文件和派生缓存已随V6提供。MuJoCo的几何、质量惯量及控制参数没有自动替换为V6；原仿真测试结果不能作为V6实机验证。

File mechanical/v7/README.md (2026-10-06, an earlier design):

# V7 屏幕前脸与居中 IMU

基于 V6 改造机身：7 寸屏嵌入前面板，D435 位于屏幕上方，HI13R2 官方模型安装在金属桥架上。造型参考用户提供的 XGO-RIDER 图片，使用独立深色屏框、相机眉部、斜切肩面和收窄侧腹；无独立上舱。腿部结构、杆长、髋膝法兰、电机位置与轮组保持 V6。

## 文件

- `wheel_leg_v7.FCStd`：原生 FreeCAD 整机，保留腿部运动表达式。
- `wheel_leg_assembly.step`：完整实体交换文件；D435 为明确标注的分析包络。
- `wheel_leg_assembly.stl`：整机装配查看；含官方 D435 ROS 可视网格，不用于整机单次打印。
- `cnc/*.step`：金属制造零件；`print/*.stl`：已摆放的独立 PETG 打印件。
- `DISPLAY.md` / `display_interface.json`：屏幕已知参数、假设、可调安装孔。
- `IMU.md` / `imu_interface.json`：官方尺寸、原点、固定方式与轴变换。
- `CHASSIS.md`：分件与装配说明；`MOTOR_LOAD.md`：本版质量和负载复核。

## 新组件

| 组件 | 数据与位置 |
|---|---|
| 7 寸屏 | 用户图165×110×20 mm、约265 g、1024×600，4×Ø3孔；孔中心距150.6377×93.3845 mm。玻璃X119，中心Y0/Z8。 |
| D435 | 官方ROS可视网格，玻璃前面X122，中心Z88；完整安装于前面板，不在机顶。 |
| HI13R2-USB-000 | 官方STEP，26×24×12 mm，预算11 g；厂家图示名义原点(X0,Y0,Z85)，底面Z79。 |
| Jetson / 电池 | 保留完整官方Orin Nano开发套件内部安装；400 g电池仍采用110×50×35 mm包络。 |

IMU 的俯视中心指左右髋轴中点/机身运动学基准，不把不规则外轮廓的面积重心当作传感器基准。厂家图示点存在标注公差，仍需实机外参标定。

## 制造范围

腿部及髋承力框采用6061-T6 CNC；IMU桥刚性连接金属侧框。前后壳、肩罩、屏框与设备托架为PETG，适配220×220×250 mm、0.4 mm喷嘴。屏幕自身孔阵列相对外框偏移及安装耳厚度未提供：已设置±2 mm调节，但最终孔偏移、隔柱长度和屏螺钉长度须按实物核对。图中小数位不代表供应商加工公差。

几何检查不等同于跳跃、疲劳、温升或动力平衡验证。本版未修改MuJoCo模型或控制器，旧仿真不能作为新增设备后实机性能证明。

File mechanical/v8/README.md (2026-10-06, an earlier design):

# V8：5寸屏、小圆角箱式机身

本版按新 GK-HD V3 规格书选择 **5寸屏**。前脸是一块完整可拆面板，屏幕在下、D435在上；机身采用平直六面与 R5 小圆角，取消斜切多折面。Jetson、相机及 HI13R2 全部安装于同一个中空机壳内。

**腿部沿用已保存的 V6 结构**：OB/AC 130mm、BW 105mm、OA/BC 45mm；髋膝法兰、嵌套关节、电机位置和轮组不变。当前保存姿态为髋轮距180mm、Beta=0°。

## 文件

- `wheel_leg_v8.FCStd`：原生 FreeCAD 装配，含运动表达式。
- `wheel_leg_assembly.step`：整机实体交换文件；D435为注明用途的分析包络。
- `wheel_leg_assembly.stl`：整机查看模型，含官方D435可视网格，不用于整机一次打印。
- `cnc/*.step`：承力金属零件；`print/*.stl`：独立PETG件，已按220×220×250mm打印机摆放。
- `CHASSIS.md` / `DISPLAY.md`：分件、装配、屏幕尺寸依据和待核对项目。
- `MASS.md` / `MOTOR_LOAD.md`：本版质量预算、24V V1.1电机负载及屏幕质量敏感性分析。
- `previews/`：实际CAD预览、前脸尺寸图、内部设备布置。

## 主要接口

| 项目 | 本版参数 |
|---|---|
| 机壳主体 | 211×164×155mm，R5，名义壁厚3mm；尺寸不含肩罩和螺钉头 |
| 完整前面板 | 148×144×3mm，R4，可整块拆下 |
| 5寸屏 | 厂家外形122×78×14.5mm；前面X114，中心Y0/Z−4 |
| 屏幕安装 | 托住金属外壳，无需在屏幕上造孔；自制托架4孔为134×60mm，Ø3.4，不是屏幕厂家孔位 |
| D435 | 前面X117，中心Z61，位于屏幕上方；官方可视模型与分析包络用途分别标明 |
| HI13R2 | 保留官方模型与刚性金属桥，厂家名义原点X0/Y0/Z85 |
| Jetson / 电池 | 内置完整Orin Nano开发套件；电池仍按110×50×35mm、400g包络 |

IMU俯视中心沿用左右髋轴中点这一运动学基准。壳体前后范围为X−94～117，包围盒俯视中心为(X11.5,Y0)，与IMU的X0相隔11.5mm；没有为外形变化移动腿部基准或IMU。实际外参需实机标定。

## 制造及验证范围

承重腿件、髋安装框与IMU桥保留金属加工；壳体、肩罩及设备托架为PETG。屏幕规格书没有提供5寸屏的安装孔位、有效显示区、质量或精确插头包络，因此没有沿用旧7寸屏孔距，也没有虚构厂家CAD。屏质量200g仅为工程估计，同时计算100/200/350g情景。

前面板四个0.5mm局部防脱止挡必须落在屏幕金属外框上，不能压玻璃；打印前须核对这一接触面和实物插头尺寸。后侧接线按留空空间检查，不代表任意直头/转接头均可装下。D435不同年份资料有1mm深度差：25.05mm配置用1mm垫片＋M3×6，26.05mm配置去垫片并改M3×5，详见[当前机壳装配说明](CHASSIS.md)。

打印文件已经平移、旋转到落床坐标，装配请使用FCStd/STEP。壳体仍需可拆支撑，不能把封闭网格和打印尺寸检查当作无支撑打印保证。Jetson维护时需拆后横框，并先抬高托盘4mm后再向后抽出，具体顺序见CHASSIS.md。

几何结果只覆盖所列静态装配、离散运动姿态及固定方向维修路径。它们不替代跳跃冲击、疲劳、散热、加工配合或控制稳定性试验。本版未更改MuJoCo模型、腿部姿态或控制器。

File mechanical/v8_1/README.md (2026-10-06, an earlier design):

# V8.1 单台样机细化版

在V8基础上细化紧固件、少量接口和安装顺序。保留5寸前脸、小R5长方体机壳、腿部杆长与嵌套关系、电机及轮组坐标；V8文件未覆盖。主承力路径为金属轮辋/下臂/关节/OB与电机法兰/髋座/金属机架，打印壳体不参与这条承力路径。

## 文件入口

- [FreeCAD模块装配体](wheel_leg_v8_1.FCStd)：M01左腿、M02右腿、M03机架、M04电器仓、M05前脸、M06外壳。
- [整机STEP](wheel_leg_assembly.step)、[整机STL](wheel_leg_assembly.stl)：总装参考，毫米；STL不是整机一体打印文件。
- [模块总装顺序](MODULE_ASSEMBLY.md)、[腿部装配](LEG_ASSEMBLY.md)、[机身装配](BODY_ASSEMBLY.md)。六个独立模块STEP位于`modules/`，保持共同机器人坐标。
- `采购与制造BOM.xlsx`：标准与目录件采购、制造分类、完整BOM三表。采购备件率默认0%，黄色单元格可调整。
- [制造与采购分类清单](MANUFACTURING_LIST.md)、[完整CSV](BOM完整.csv)、[制造CSV](制造件分类.csv)、[采购CSV](标准与目录件采购汇总.csv)。
- [关键配合与首件验收](LEG_FITS.md)；塑料孔槽、盲孔螺纹和机架要求另见机身装配文件。
- [电池结构与预留空间](BATTERY.md)、[电池官方资料核对](BATTERY_SOURCE_REVIEW.md)、[质量预算](MASS.md)及[电机与电池负载](MOTOR_LOAD.md)。
- `manufacturing/print/`：11种通用化后的打印型号，独立STL与STEP；`manufacturing/metal/`：24种金属制造型号STEP。**数量按BOM，不按文件数或左右装配对象数重复下单。**

## 本次实际调整

|项目|V8.1处理|
|---|---|
|屏幕与机壳螺钉|M3×22改20，机壳M3×14改12，保持设备及前脸位置|
|相机后座|并为一体6 mm厚后横梁，统一M3×8，取消两片1 mm定制垫片|
|关节铜套与隔圈|合并为内/外两种一体带肩青铜套，减少12个独立散件|
|髋转子定位销|改为DIN6325 Ø4m6×10；法兰盲孔深度相应调整，按实物限深安装|
|关节销|保持外形，双端M2完整牙深≥4.3、底孔深4.6，给标准螺钉保留顶底余量|
|漏建紧固件|补上12颗轮辋螺钉、24颗机架及托盘螺钉；新增的真实螺钉头促成Jetson夹座局部让位|
|共用制造型号|髋座、髋转子法兰、OA、AC、轮辋、前后横框、左右肩罩可按已验旋转关系共用；其余左右手性件继续分开|
|结构分块|保留整根承力件、可拆机架和大块壳体，未增加碎片式角码或大量热熔嵌件|
|新电池|替换110×50×35旧占位；按用户图纸85.6×61.6×42、含磁底44.5设计窄托，一体PETG托盘保留4颗M3×8，可带电池预装成模块|

原主结构35种，加旧小件7种及相机垫片1种，共43种88件定制制造件；本版35种74件。这个比较仅针对定制制造件，不能与补齐建模后的紧固件总数混比。

## 单机数量

|类别|型号数|净用量|
|---|---:|---:|
|PETG打印件|11|12件|
|金属制造件|24|62件|
|通用标准件|16|174件|
|指定厂家目录件|4|64件|
|电机、设备及轮胎等|8|13件|
|软垫和电池束带|2|6件|

金属制造件包括18种主结构共24件，以及6种小型定制件共38件。其中两种薄压盖/防脱片适合精密薄板加工，其余采用CNC铣削、车削和必要的精磨/二次加工。标准件与目录件合计20种238件；目录件包括两种NBK小头螺钉、一种NBK超低头M2螺钉和一种NSK 626ZZ1轴承。

BOM逐一覆盖326个物理CAD表达，其中D435的分析包络和官方网格只算一台相机。原厂设备内部螺钉不重复拆计。电池已由用户确认采用24V等级E626S，外形按新图纸；整套含磁底仍用400g质量预算，接头空间需实测；轮胎和电源转换、保险/急停、线束等仍有待选项。

## 总装先后关系

1. 预装左右整腿；在裸髋座阶段预放四颗M4×12，临时防掉。
2. 预装金属机架，保持电器仓为空，保留机内工具空间。电池和窄托在机外预装并穿好两条束带。
3. 整腿在180 mm髋轮距靠入机架，垫片与螺母从内侧放入；后上螺钉在110 mm姿态锁紧，其余三颗在165 mm姿态锁紧。两腿均需工装支撑，移出工具后才能调姿态。
4. 从上方放入整套电池/托盘模块，锁紧4颗M3×8，再装已预装的Jetson托盘及IMU桥。
5. 装前壳，再安装已预装的屏幕/相机前脸；布线检查后装后盖和肩罩。

新窄托消除了旧58mm宽托盘的后装干涉，整托+电池+底部单层束带的100mm连续竖直扫掠已检查。更换电池模块需先腾出上方主机托盘通道。工具及坐标限制以模块装配文件为准。

## 制造时的重点

- 承力金属不能根据外观直接替换PETG；带台阶、轴承座及凸台的铝件不能把板材毛坯直接视为普通钣金成品。
- 金属加工以STEP和书面公差共同为依据。CAD中许多螺纹用底孔表示，完整牙深、孔底余量、去毛刺和表面处理遮蔽必须落实到加工工艺；STL不用于精密配合验收。
- A/B/C使用同一种6×19×6轴承。先测轴承和加工孔，铜套肩按实测叉距选配，避免用端部M2把轴承预紧或叉耳拉弯。限位销只用于装配限位，不能承担带电撞停。
- 指定沉头件为DIN7991目录尺寸；M3头Ø6/k1.7，M4头Ø8/k2.3，不能无条件代换大头ISO10642。HI13R2的M2.5螺钉须核对光头Ø≤4.5。
- PETG打印孔、捕获螺母槽和壳体舌槽先做同方向试片。保持220×220×250 mm打印包络，壳体使用可拆支撑；不要整体缩放补孔。
- D435后座按实物深度选25.05或26.05 mm版本，后一版本在`alternates/`，为替换件。5寸屏规格书未给完整安装孔及玻璃边界，使用外框托夹，首件确认四角只压金属外框。
- 新电池安装范围X±42.8、Y±22.25、Z−43.8～17.8mm；每侧0.5mm装配间隙，采用两条10×300mm束带，底部单层厚≤1mm。DC侧朝上，设计预留11mm插头/走线高度；真实孔位和弯头尚未给尺寸，不能把该检查区当作已验证的插头。详见[BATTERY.md](BATTERY.md)。

## 验证范围

- FreeCAD原生主腿杆、髋座、膝杯、轮辋、电机和轮胎共30个对象的体积、表面积、包络与运动表达式对比V8一致。
- 100～215 mm、每5 mm一档，共24个腿长姿态，Beta=0°，受检刚体相对运动对未发现超出0.05 mm³阈值的实体相交。不是连续全工况证明。
- 276个外部连接硬件对象在100/180/215 mm姿态的原生摆位检查通过。
- 整腿携预装M4的10个轴向接合位置、指定外内工具通道、新电池模块的连续保守落入包络均完成检查。手掌、手柄、线束和连接器实物不在这些几何包络内。
- 全部独立PETG STL封闭、法线一致，无被检测到的非流形或自相交；摆放尺寸满足打印机限制。制造共用件以双向布尔差检查，而非只凭左右外观判断。
- 工作簿数量与CAD实例逐项核对；Excel公式由artifact-tool重算并测试备件比例，未在原生Excel应用引擎中测试。

证据文件：`preserved_geometry_review.json`、`validation.json`、`battery_integration_review.json`、`battery_local_review.json`、`native_hardware_placement_validation.json`、`module_access_review.json`、`body_detail_review.json`、`print_mesh_validation.json`、`bom_cad_audit.json`及`bom_workbook_review.json`。维修路径若有追加复核，以`maintenance_access_review.json`注明的实际范围为准。

本版用于单台样机制造准备和首件试装。未完成落地冲击、疲劳、驱动器热负载、散热及真实线束寿命验证，因此不能据几何检查认定已满足跳跃要求；实际电池、屏幕质量和载荷仍应带回动力学核算。

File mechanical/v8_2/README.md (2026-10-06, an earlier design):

# V8.2 电气与后部接口集成

在V8.1基础上加入顶部自锁电源开关、后部充电接口安装板、双路USB2CAN、用户分配PCB、24→19 V转换器及四口USB扩展坞。保留5寸前屏、上方D435、小圆角机壳和腿部机构；Jetson、IMU、电池与两腿位置沿用基线。

## 文件入口

- [FreeCAD装配体](wheel_leg_v8_2.FCStd)：M01～M08模块及可隐藏的走线预留组。
- [整机STEP](wheel_leg_assembly.step)、[整机STL](wheel_leg_assembly.stl)：毫米制总装参考，STL用于查看整机，不能拿整机文件一体打印。
- [结构STEP](wheel_leg_structure.step)：打印及CNC结构件组合；[模块清单](module_manifest.json)对应`modules/M01.step`～`M08.step`，保持共同坐标。
- [模块安装顺序](MODULE_ASSEMBLY.md)、[电气集成与未确认项](ELECTRICAL_INTEGRATION.md)、[功能接线图](WIRING_TOPOLOGY.svg)。
- [内部结构标注图](previews/internal_structure_annotated.png)：模块位置与背部接口布置。
- [走线参考STEP](wiring_route_reference.step)、[路由说明](routing_allowances.json)：空间规划占位，独立于实物总装导出。
- `采购与制造BOM.xlsx`及[制造分类清单](MANUFACTURING_LIST.md)：一台样机净用量；相同标准规格合并，备件率默认0%。最终数量以本版完整BOM和CAD覆盖检查为准。
- `manufacturing/print/`提供独立打印STL/STEP；`manufacturing/metal/`提供金属制造STEP。按BOM数量下单，不按左右装配文件重复计数。

## 结构布置

|部件|本版布置|
|---|---|
|M16自锁开关|顶部X60/Y0，Ø16.3安装孔、3 mm壁；按47.5 mm带插座总深保留|
|USB2CANFD Dual|一体服务架上平放，Type-C朝−Y；采用供应商模型中的裸板，去掉原外壳和壳螺钉|
|用户分配PCB|前部下方竖置，板面约X66，Y5～37/Z−13～26；DC口朝上，背板穿过电子盘槽|
|24→19 V模块|负Y侧支臂，主体45×25×20、总长58、安装孔距51；仅按尺寸图建模|
|四口扩展坞|后盖内X−91～−61/Y±52/Z0～10，四口共用后部窗口；一体底托加可拆压托|
|后充电口|背视右下Y−46/Z−25，可换小板仅有Ø3定位导孔；母座型号确定后再完成最终孔|
|腿部走线出口|机壳两侧X89/Z54、Ø10孔；3 mm板厚，护线套净孔≥7待选|
|内部过线|电子盘后缘7 mm宽U形开口槽，中心X−75/Y25，供扩展坞不可拆线从侧向放入；服务架X70/Y21另有Ø8.6孔，中央腿束通道宽10 mm|

新增服务架、扩展坞压托和充电安装片可PETG打印；修改的前主壳、后检修壳及电子盘均保持原材料分类。金属承力件和腿部运动结构不因本次电气集成改为打印件。

开关、转换器和扩展坞使用用户尺寸图建立外形；两块板采用提供的真实STEP。形状模型不包含可验证的PCB导电网络，电源分配的线序和额定值仍需电气资料/实测。

## 接线与维修

电池共口一分二：充电支路在总开关前，负载支路经过顶部开关后分别供给电机分配及24→19 V模块。电机动力电气并联；每条腿的CAN顺接髋、膝、轮，左右为两路独立总线。USB2CAN的供电和上位机数据来自USB，不从CAN口输入电池电压。

Jetson四个Type-A分别接D435、USB2CAN、屏幕USB和背部扩展坞；Type-C Host接HI13R2，DisplayPort经DP→HDMI接屏幕。扩展坞原150 mm线增加一根250 mm USB3 A公母延长线，绕机体正Y侧高位布置；背部四口全部保留给外接设备。后盖可连扩展坞作为整体拆下，充电口用独立小板便于后续换型。

安装遵循“两腿与空机架→电池→电子盘/M07→IMU→带开关前壳→前脸→带扩展坞后盖→肩罩”。支架底部螺母、板卡和转换器都先在机外完成，避免在满装电器仓内散装小零件。新增竖板改变维修包络，旧版Jetson后抽路径不能直接移用。

## 证据范围与待完成项

- `electrical_build.json`记录改动对象、新增硬件和基线哈希；[最终电气结构检查](electrical_final_validation.json)记录实体相交及基线对象保留情况；[路由空间检查](routing_validation.json)记录预留走廊及`all_clear`结果。使用报告时核对版本/哈希，`all_clear`只代表所列占位几何的检查，不代表真实线缆已验证。
- 基线腿部装配、公差、已选紧固件和历史检查保存在`baseline_v81/`。本版新件不能只引用旧检查通过。
- 走线对象只表示预留空间，没有证明实物插头可插入、弯曲半径合格或腿部动态线束寿命。接头尺寸、护线件和线束下料需试装落实。
- 后部DC母座的安装螺纹/孔径未给；现有Ø3是导孔。顶部开关DC分断能力/LED电压、转换器输入范围与功率、用户板的网络/载流尚未确认。
- E626S持续6 A；满充25.2 V不可直连Jetson。J4310 V1.1手册最低工作电压表述不一致，本版按更严格20 V审查，不能把电池18 V截止视为可用运行下限。现有供电未获跳跃能力验证。

本版用于模块装配、加工准备及样机试装；原始V8.1未覆盖。完整验证结果、数量和质量以本版相应报告为准，外购设备的未测质量保持工程预算标记。

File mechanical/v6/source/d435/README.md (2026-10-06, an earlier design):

# D435 官方模型与导入说明

`d435_official_ros.dae`来自[RealSense官方ROS仓库](https://github.com/realsenseai/realsense-ros/blob/ros2-master/realsense2_description/meshes/d435.dae)，原始时间戳2018-07-03、单位米。源文件保留不变；`d435_official_ros_mm.stl`仅把原始三角形坐标乘1000转为毫米，保持原顺序/绕向，未补洞、平滑、简化或重画。STL不保留DAE材质颜色。

官方较新的SolidWorks模型`D435_Solid.SLDPRT`另行保留；本机FreeCAD无法原生读取该格式，因此没有把ROS显示网格称作精确实体CAD。碰撞及质量仍采用明确标注的保守包络与75g质量，显示网格不重复计质量。

| 检查项 | 结果 |
|---|---:|
| 几何组 | 18 |
| 三角面 | 231186 |
| 边界边 | 80034 |
| 非流形边 | 0 |
| 退化三角面 | 56 |
| 朝向不一致面 | 5 |
| 是否闭合实体网格 | 否 |

装配变换为原毫米坐标`(x,y,z)→(z+100,x,y+19)`，前表面保持X100，相机中心Z19。源包络89.9143×25×25.0547mm。两后安装孔在源`(±22.5,0)`，孔口平面z−25.05，装配后为X74.95、Y±22.5、Z19。当前独立质量/碰撞解析模型为X74.95～100、Y±45.075、Z6.425～31.575mm；官方网格最后端有约0.0047mm局部凸出，此解析模型仍是名义尺寸近似，不能代替精密接触面计算。

2025版D400数据页140、图10-9标注D435/D435i总深26.05mm，与2018显示网格的25.05mm相差1mm。两者不能作为同一精确尺寸使用。当前支架后接触面X73.95，保留两个可拆1mm垫片：25.05mm模型配1mm垫片和M3×6，26.05mm实物移除垫片、换M3×5，两者名义进入深度均2mm。后一配置的解析模型应延伸至X73.95；实物按实际后安装面选择配置。后M3最大进入深度按官方图纸3mm，不能按ROS网格约1.60mm的孔内可见长度推定加工深度。推荐紧固力矩来自同图纸0.4N·m。

网格来源许可证为Apache License 2.0，已保存`LICENSE.realsense-ros`与包级`realsense2_description.package.xml`。转换说明见`NOTICE.conversion.txt`；完整哈希、拓扑检查和后安装面顶点证据见[mesh_inspection.json](mesh_inspection.json)。

可复现：`/Applications/FreeCAD.app/Contents/Resources/bin/python tools/inspect_v6_d435_mesh.py`。整机展示STL包含该官方开放网格时，不应宣称整机STL全部水密；加工件STL需单独验证。

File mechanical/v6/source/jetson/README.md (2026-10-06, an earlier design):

# NVIDIA Jetson Orin Nano 官方整套开发套件

原始文件来自[NVIDIA官方下载](https://developer.nvidia.com/downloads/assets/embedded/secure/jetson/orin_nano/docs/jetson_orin_nano_devkit_3d_step_model.zip/)，2026-09-22匿名下载HTTP200。当前[官方下载目录](https://developer.nvidia.com/embedded/downloads.json)标注版本 **20230320**、发布日期2023-03-21；STEP自身时间戳2023-02-03。目录原文及完整SHA256见[provenance.json](provenance.json)。

模型包含P3768 A04载板、P3767模块包络、散热器、风扇、塑料底座及WiFi/NVMe等装配内容。它是厂商发布的完整开发套件机械模型，其中SOM仍是厂商明确标注的组件包络，不是内部热分析/惯量模型；可选NVMe/WiFi内容不一定等于用户实际配置。

| 文件 | 用途 |
|---|---|
| jetson_orin_nano_devkit_3d_step_model.zip | 原始下载包，未改动 |
| P3766-P3768SKU4-P3767ENVELOPE.stp | 原始官方STEP，未改动 |
| jetson_devkit_native.brep | 原始几何原生缓存 |
| jetson_devkit_solids.brep | 保留全部1393个有效实体，去除527个非实体辅助壳；未缩放、重画或替换实体 |
| official_devkit_preview.png | 系统FreeCAD生成的实物几何预览，颜色仅用于辨认组件 |

原始BRep控制包围盒为103.379×91.066×34.905mm；实体缓存的控制包围盒为103.379×91.053×34.905mm。该包围盒最低Z−5.038511包含曲面控制点扩展，**不是底座实际承托面**；实际底面Z−4.9。

源坐标前方连接器朝−Y。建议绕Z轴+90°，再平移(1.663251,−46,37.9)mm，使原底座真实底面恰好接触机身托盘Z33、连接器朝机器人+X。此时实际高度范围Z33～67.766mm，BRep控制包围盒仍会延伸到Z32.861489，不应据此判断穿入托盘；应检查实际实体布尔交叠与面间距离。外部夹条防抬唇下表面Z40，相对原底座最高边缘Z39.5留0.5mm间隙。此修正只改变装配位姿，原厂STEP及两个缓存均未改形。

载板四孔D2.75、孔距86×58mm，但它们已用于原塑料底座装配。底座下方有盲孔/塑料成型细节，不能把载板孔直接当作整套贯通安装孔。保留原底座时采用外围托架/压块，新增M3仅连接托架本身。

可复现检查：`/Applications/FreeCAD.app/Contents/Resources/bin/python tools/inspect_v6_jetson.py --render`。脚本核对原始STEP哈希，保留厂商文件，输出原生缓存与几何来源记录。

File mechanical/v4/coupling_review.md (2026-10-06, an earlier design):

# V4 两件套嵌电机法兰

本页对应 `tools/cad_v4_coupling.py`、本目录 `coupling_review.json` 和 `cnc/` 内左右版 STEP。髋膝连接法兰每腿两件、全机四件；材料基准为 CNC 6061-T6，单位 mm。属于制造审查原型，尚未通过扭矩、疲劳或实物装配试验。

[法兰剖面、孔系和装配顺序 SVG](cnc/coupling_section.svg)／[PNG 预览](cnc/coupling_section.png)。图中为右腿件；无后缀 STEP 对应右件，`_left.step` 对应左件。左右杯件孔系不能直接翻面互换，制造角相位以相应 STEP 为准。

## 零件拆分与连接关系

| 零件 | 构成 | 连接对象 |
|---|---|---|
| `hip_rotor_cnc` | D39 定位颈和 D43 套柱，一体车削；正面 D35.05 定位凹口；3 个 D4 定位销孔；6 个轴向 M3 通孔和沉孔；4 个径向 M3 盲螺纹孔 | 髋 4310 转子 |
| `knee_stator_cnc` | 外径 D57 的杯件，外径与 4310 外壳一致；内孔 D43.05、套入深 7；底盘承接 4 个 M3 膝电机后壳螺钉；侧边 4 孔锁紧 | 膝 4310 后壳／定子 |

传力路径为：髋转子 → 小法兰 → 四个径向螺钉及套嵌定位面 → 杯件 → 膝电机后壳。两件法兰相对固定，径向孔是杯件的通孔、小法兰上的螺纹孔；不会把两个孔都攻牙。

小法兰在 Y=72.2～80.5 保留 D39 颈部，通过已有髋支架的 D40.4 开口；Y=80.5～87.5 才扩大到 D43。杯件 Y=80.5～94，膝电机后壳安装面为 Y=94。该结构不改变两电机现有轴向基准。

## 真实电机接口

采用用户提供的 `DM-J4310-2EC-V1.1_3d_20260228_1.stp`，并与 V1.1/V1.2 电机图复核。源文件相对旋转 X=180° 后，转子定位销为 3×D4、PCD24.30、角度 90°/210°/330°。电机孔深 4，本版销入电机 3、入法兰 6，总长 9。

转子 6×M3 位于 PCD27，使用 M3×12：头下从 Y=82 至 70，转子面 Y=73，名义入牙 3。膝后壳 4×M3 位于 PCD38，相位 45°，使用 M3×6：头下从 Y=91.5 至 97.5，后壳面 Y=94，名义入牙 3.5。

三根定位销在模型中为 D4。制造时需按实物电机孔选配：法兰端采用固定配合，电机端采用可拆的定位配合；电机端不得未经测量直接使用全长过盈销。与三孔位置及 D35 定位口共同核对后再定最终销公差。

## 径向锁紧及加工

- 4×M3×8 内六角圆柱头，圆周角度 15°/105°/195°/285°，轴向中心 Y=84。
- 杯件径向通孔 D3.4；沉孔 D5.8，头下承压面半径 R25.3。
- 小法兰 M3×0.5 螺纹，名义入牙 4.2；D2.5 底孔圆柱有效深 5，另留 118° 钻尖。采用底攻完成不少于 4.2 的完整螺纹；完整牙深和螺钉不顶底均需实际检查。
- M3 螺钉头模型按 D5.5×高 3，最外包络小于 D57；头部不会突出电机圆柱包络。
- 建议套柱 D43 公差 0/−0.02，套孔 D43.05 公差 +0.02/0，形成 0.05～0.09 的直径间隙；该公差建议尚未进行实物配合验证。
- 非定位锐边去毛刺；套合入口可做小导入倒角，避开承压面和销孔有效长度。

杯底 4 个轴向 D5.8 工具通道与套孔自然连通，因此从杯口能将螺钉和内六角扳手送到后壳安装位。四个径向孔避开这些通道与小法兰的转子螺钉沉孔。

## 装配顺序

1. 将定位销固定于小法兰；对正髋转子的定位孔和 D35 定位圆，以 6×M3×12 固定小法兰。此时外侧六个螺钉头完全可达。
2. 从杯件开口装入 4×M3×6，将杯件固定在膝电机后壳。此时轴向工具通道完全开放。
3. 对准四个侧孔，将杯件沿轴线套入小法兰 7；确保杯底与小法兰端面贴合。
4. 装入四个径向 M3×8，按对边顺序均匀锁紧。拆卸时先卸径向螺钉，再将电机与杯件轴向移开。

## 已运行的几何验证

- 两个 CNC 零件和 17 个硬件均为有效单实体，完成 BRep 检查。
- 包含两只原始 4310 电机 STEP 的局部装配：没有大于 0.001 mm³ 的相交。
- 全部硬件处于 D57 外包络之内。
- 6 条髋转子、4 条膝后壳、4 条径向内六角工具路径均畅通，工具按包络半径 1.45 检查。
- 杯件轴向工具通道到径向通孔的最小几何余肉 **6.336**；小法兰轴向沉孔到径向底孔（含钻尖）的最小余肉 **1.224**。

上列结果为静态 CAD 几何检查。完整机身中的装配状态及运动检查由整机报告覆盖。为了避免原始电机刚体 STEP 中固定不动的转子孔造成假碰撞，整机硬件省略了销在转子内部的 3 mm；本局部文件使用完整定位销，并检查了真实电机孔。

紧固件头部尺寸参考：[Bossard ISO 4762 / DIN 912 M3 产品数据](https://bossard.partcommunity.com/3d-cad-models/bn-3-hex-socket-head-cap-screws-fully-threaded-din-912-iso-4762-cl-8-8-zinc-plated-blue-bossard-catalog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)。

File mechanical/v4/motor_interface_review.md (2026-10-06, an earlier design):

# V4 电机接口复核

原始图纸和 STEP 确认：**4310 转子有 3 个定位销孔**，与 6 个 M3 螺纹安装孔不同。可按用户要求设计带定位销的小法兰，并用第二个杯状法兰连接膝电机后壳。当前两件套筒已完成局部装配和工具通道检查；完整尺寸见 INTERFACES.md。

## 原始资料确认的尺寸

| 接口 | 原始证据 | 机器人右侧相位（X=r·cosθ，Z=r·sinθ） |
|---|---|---|
| 转子销孔 | 3×Ø4，图纸公差 +0.02/+0.04，PCD 24.30；STEP 几何深 4 | 90°、210°、330° |
| 转子安装孔 | 6×M3，PCD 27，深 5 | 0° 起每 60° |
| 前定子安装孔 | 6×M3，PCD 50，深 5 | 30° 起每 60° |
| 前定子定位孔 | 2×Ø3，+0.02/+0.04，深 5；PCD 50 来自 STEP | 105°、285° |
| 后定子安装孔 | 4×M3，PCD 38，深 4 | 45° 起每 90° |
| 外形 | 壳体 Ø57，输出转子 Ø35，壳体轴向 45，总长 46 | 同轴，输出面高出前定子面 1 |

销孔深 4 mm 来自 STEP 圆柱孔壁，二维图未单独标注深度。新读原 STEP 后，在三个孔内分别放置 Ø3.98×3 mm 实体探针，检查全部 26 个电机实体，均无占用。建议定位销伸入电机 3 mm，留约 1 mm 底隙；嵌入自制法兰的长度和压入配合另按加工图控制。Ø4 孔的 STEP 名义值不能代替二维图的正公差。

“同心等高”不能解释为两个前端面完全齐平：源坐标输出面 Y=-0.5、前定子面 Y=+0.5、后定子面 Y=45.5。右侧采用 X 轴旋转 180° 后，髋输出面 Y=73，前定子面 Y=72；膝后定子面 Y=94，输出面 Y=140。围住 Ø35 输出凸台的结构必须避开相对旋转的定子面。

2026-09-08 两份 V1.1/V1.2 使用说明书第 9 页的上述安装尺寸，与 Ver.B20230904 图纸一致。本次采用的三维模型文件明确为 V1.1；不据此推断两版本其他内部结构完全相同。

## 当前两件杯套方案

当前构型已调整为 **Ø39 颈部 / Ø43 插芯小法兰 + Ø57 杯件**。插芯 Ø43 配杯孔 Ø43.05，套合深 7 mm；四个径向 M3×8 螺钉位于 Y=84、相位 15°/105°/195°/285°。它们穿过杯壁 Ø3.4 通孔，拧入插芯的 M3×0.5 盲牙。径向与轴向孔系错位，不依靠紧定螺钉压在光圆柱上的摩擦保持连接。

髋转子通过 3 个 Ø4×9 定位销、6 个 M3×12 螺钉连接小法兰；定位销伸入电机 3 mm、嵌入小法兰 6 mm。小法兰保留 Ø35.05、深 0.8 的浅定位凹杯。杯件用 4 个 M3×6 螺钉固定在膝后定子，四条轴向沉孔兼作螺钉头和工具通道，允许先连接各自电机再套合。

当前 [局部 FreeCAD 复核](coupling_review.json) 表明：两件法兰及所建五金均为有效单实体；包含真实电机及完整定位销的检查未发现超过 0.001 mm³ 的相交；所建工具探针路径无相交。杯件轴向工具通道与径向通孔最小几何间隔为 **6.3357 mm**，转子法兰轴向头孔与径向攻牙底孔最小几何间隔为 **1.2240 mm**。这些数值描述孔系几何，不是整件最小壁厚或额定承载能力。

径向孔模型是 Ø2.5 底孔，圆柱深 5 mm，并包含 118° 钻尖；必须另用底攻完成至少 4.2 mm 有效完整螺纹，再检验实物螺钉。STEP 不含真实螺旋牙型，装配五金省略啮入螺纹段。详细尺寸、配合和装配次序见 [INTERFACES.md](INTERFACES.md)。

## 已弃用候选的历史记录

早期 Ø39 插芯、6 个径向孔方案的杯壁局部余肉仅 0.5156 mm，因此没有作为当前设计采用。原始计算保存于 `source/motor_review/candidate_cup_access_web.json`，JSON 中归档为 `candidate_rejected`。这项历史结果不能表述为当前 Ø43 / 四孔方案尚未修复的缺陷。

## 可追溯证据

- [接口数值及源文件 SHA-256](motor_interface_review.json)
- [重新读取原 STEP 的圆柱面数据](source/motor_review/J4310_fresh_step_probe.json)
- [三个销孔的实体插入检查](source/motor_review/pin_insertion_probe.json)
- [杯套候选孔间余肉计算](source/motor_review/candidate_cup_access_web.json)
- [Ver.B20230904 原图页渲染](source/motor_review/J4310_VerB20230904.png)
- [标注图原图页渲染](source/motor_review/J4310_annotated.png)
- [V1.1 2026-09-08 说明书第 9 页](source/motor_review/J4310_V11_20260908_p09.png)
- [V1.2 2026-09-08 说明书第 9 页](source/motor_review/J4310_V12_20260908_p09.png)

原 PDF/STEP 绝对路径及哈希保存在 JSON。本复核确认厂商几何接口，并引用当前两件套筒的局部几何检查；没有修改电机原文件或模型构建脚本。公差闭环、锁紧扭矩及承载能力仍需实物验证。

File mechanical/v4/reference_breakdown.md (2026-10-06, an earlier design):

# 参考图拆件与厚度复用分析

本文件先按用户参考图拆解机构，再区分本机器人为打印、CNC 加工、轴承安装和维修新增的结构。图纸是一张示意渲染图，不含尺寸和完整剖面；以下不从透视图推定精确厚度、隐藏销孔或紧固件规格。配套的 [矢量拆解图](previews/reference_breakdown.svg) 为重新绘制的原理示意，不是参考图零件的尺寸复刻，也不是生产图。

参考原图：[已归档用户参考图](source/reference_mechanism.png)。

## 1. 先把参考图的零件分开

| 编号 | 可分离实体或组件 | 参考图中直接可见 / 用户明确的信息 | 不能从图确定的信息 |
|---|---|---|---|
| R01 | OB 内侧完整上连杆板 | 用户明确 OB 由两件组成；侧视和爆炸视图可见平行板及厚度边线，内板从 O 连续到 B | 板厚、内板实际孔系、两板连接柱的位置与数量 |
| R02 | OB 外侧完整上连杆板 | 绿色大圆头、连续臂身、B 圆头及三角镂空；与 R01 共同夹住 B 处的下连杆 | 圆头内有无独立滚动支承、轴肩及内部螺钉细节 |
| R03 | OA 膝曲柄组件 | 紫色 O 端圆形连接区和 A 端短曲柄；A 处具有厚度方向的双侧夹持关系 | 内外耳是否一体加工，或由两件固定成叉；中央连接座的背面细节 |
| R04 | AC 连杆 | 红色细长双孔杆，两个圆头；A、C 均嵌入对应叉口 | 孔内使用轴承还是滑动衬套、轴向止推结构 |
| R05 | CW 下连杆组件 | 青色长下杆，C 叉部、B 转动处和 W 末端为同一运动刚体；有连续曲线边界和镂空 | 叉部是一体加工还是拆片拼装，隐藏背面结构、确切板厚 |
| R06 | 足端盖 | 粉色独立端盖；爆炸视图中与下杆、足端分开 | 接口尺寸、材料与内部紧固 |
| R07 | 足端 | 黑色足端 | 本机改轮端，原结构不复用 |
| R08 | 膝俯仰电机 | 黑色圆柱执行器，输出驱动 OA，定子随 OB 所属刚体运动 | 图中型号、安装孔和输出定位方式 |
| R09 | 髋俯仰电机 | 与膝电机同轴布置，其输出带动膝静壳和 OB | 图中联轴零件的精确制造分界和连接方法 |
| R10 | 髋横滚电机及支架 | 参考图最右端执行器和支架；用户已标注删除 | 本机不复用 |

图中黄色圆盘、浅色隔环等存在遮挡，不能逐个断言为转子法兰、轴承或电机本体零件。对本机，这部分应使用真实 DM-J4310-2EC 模型和原厂二维图重新确定。尤其不能把圆柱外观相同理解为两端安装孔也相同。

**可从图和用户要求确认的是运动实体与嵌套关系；不能确认所有隐藏制造件的精确数量。** 因此，把 OA、CW 设计为可拆内件与外耳，是本机的装配方案，不作为对原图制造分件的事实声明。

## 2. 三处关节的承载拓扑

| 关节 | 从内侧到外侧的结构 | 固连关系 | 运动关系 |
|---|---|---|---|
| A | OA 内耳 → 轴向间隙/止推件 → AC 端舌 → 止推件/间隙 → OA 外耳 | 两片 OA 耳与 O 端连接座刚性连接 | AC 相对 OA 绕 A 转动；金属轴由 OA 两侧支承 |
| B | OB 完整内板 → 间隔/止推件 → CW 中央舌 → 止推/间隔件 → OB 完整外板 | 两片 OB 在 O 端及臂身适当位置刚性连接 | CW 相对 OB 绕 B 转动；金属轴两端均落在 OB 完整板上 |
| C | CW 内耳 → 间隙/止推件 → AC 端舌 → 止推件/间隙 → CW 外耳 | 两片 CW 耳与下连杆刚性连接 | AC 相对 CW 绕 C 转动；金属轴由 CW 两侧支承 |

“嵌套”须沿厚度方向判断：活动舌的两个外侧面均位于叉耳内侧面之间。只在图上把两块板叠到一起，或只在一个侧面增加一片垫板，均不能建立上述两侧支承关系。

双侧支承能建立双剪受力路径，但不等于轴、PETG 耳板和轴承已有承载评级。孔边距离、轴弯曲、耳板张开、层间强度和装配间隙仍需校核。

## 3. 将原图的结构复用到本机器人

最终保留以下制造分件，支持 PETG 分件打印、OA 两件 CNC 和轴承装入：

| 本机零件 | 来源关系 | 设计目标 |
|---|---|---|
| OB 完整内板 | 直接复用参考拓扑 R01 | 与膝定子固定，围绕 O 留出真实转子和 OA 的转动空间 |
| OB 完整外板 | 直接复用参考拓扑 R02 | 从 O 连续到 B；不能以局部 B 耳替代完整板 |
| OA 主件与外耳 | 参考 R03；拆成两件是本机新增 | 6061-T6 CNC；A 两耳各 3 mm 包住 AC；O 中心盘向内嵌入 1 mm，不把整块 OA 放在 OB 外侧 |
| AC 连杆 | 直接复用参考拓扑 R04 | 两端为承载舌，中段为较薄的曲线杆身；轴承座为局部增厚 |
| CW 主件与外叉板 | 参考 R05；可拆外叉板是本机新增 | B 中央舌嵌入 OB；C 两耳围住 AC；W 改真实 H6215 安装接口 |
| 髋输出转子法兰 | 用户本次指定的新结构 | 小直径实心套芯，与真实转子定位和孔系连接 |
| 膝定子杯形法兰 | 用户本次指定的新结构 | 上端连接真实膝静壳，下端为空心圆柱，与转子法兰同轴套合，侧向一圈锁紧螺钉 |
| 轮端安装和轮圈 | 替换 R06/R07 | 使用 H6215 原始模型接口；不保留图中的足盖和橡胶足 |

不把定子杯侧向锁紧螺钉简单等同于可靠传扭的摩擦锁紧。套合长度、配合、螺钉端型、止退和传扭路径由法兰专项设计记录说明。转子定位销的位置也必须有原厂孔图或模型证据，不能由参考渲染图推定。

## 4. V3 为什么显厚

V3 右腿 OB 内板为 Y=139～147，外板为 Y=184～192，因此腿部夹层结构的总宽度是 **53 mm = 8 + 37 + 8**，不含挡圈和螺钉外伸。

A/C 自身已经占 **32 mm = 8 + 1 + 14 + 1 + 8**：两个 8 mm 叉耳、两片 1 mm 轴承内圈止推垫片、14 mm 的双 626 轴承舌。B 的中央舌仍只有 14 mm，却放在 37 mm 的 OB 空腔内，需要 11 mm 和 10 mm 的长隔套以及两片 1 mm 垫片填补。OA 外耳延伸到整个堆叠的外层，使 O 端桥接座进一步变长。

所以厚度应由**共同的嵌套层面**控制，而不是在 OA、AC、CW 各自设计完后再逐层向外堆放。轮端应随新的 CW 主平面定位；只把电机向内平移而不重建完整层面，会产生新的局部相交。

## 5. 最终复用方案：33 mm，共层外板与薄 CNC 曲柄

最终 V4 让 **OB 外板、OA 外耳和 CW 的 C 外帽共用 Y=166～172 的外侧层面**。这些零件在 XZ 平面占据不同位置，并非实体相交：OA 位于 O 中心及左侧曲柄区，OB 外头保留右侧 C 形承载环和连续 O→B 板，CW 的 C 外帽与连接柱位于 AC 扫掠的背侧。OA 外耳只占共同层的前三毫米；中心盘又向内嵌入 1 mm。

| 元素 | 右腿 Y 区间 / mm | 厚度 / mm |
|---|---:|---:|
| OB 完整内板 | 139～145 | 6 |
| C 内耳 | 146～152 | 6 |
| A CNC 内耳 | 149～152 | **3** |
| A/B/C 内侧内圈垫片 | 152～153 | 1 |
| AC 端舌及 CW 的 B 舌 | 153～165 | **12** |
| A/B/C 外侧内圈垫片 | 165～166 | 1 |
| OB 完整外板 / CW C 外帽 | **166～172，共层** | 6 |
| OA CNC 外耳 | **166～169，嵌在共同层内** | **3** |
| OA CNC 中心盘 | 165～170 | 5；沉孔底 167，承压厚 2 |

总结构宽度为 **33 mm = 172−139**，相比 V3 的 53 mm 减少 20 mm（约 37.7%）。尺寸只计定制腿部结构，不包含光轴、挡圈和螺钉头的局部外伸。

用户授权 OA CNC 和轴承重选后，OA 两件改为 6061-T6，A 两耳各从 6 mm 进一步减到 3 mm；中部开 Ø12 贯通减重孔，仍保留真实转子定位杯、6×PCD27 孔系和完整承载环。内桥在 Y=165 结束，外中心盘从 Y=165 嵌入，6 个 M3×30 圆柱头螺钉位于沉孔底 Y=167，名义夹持 27 mm、进入转子 3 mm；螺钉头顶 Y=170，与外中心盘表面齐平。

三处仍各使用**两只 NSK 686AZZ1（6×13×5）**，中间保留 2 mm 金属内圈隔套；总舌厚由 14 mm 减到 12 mm。必须选双防尘的 686AZZ1，不能误用宽 3.5 mm 的开式 686A。NSK 官方安装表要求内圈挡肩外径不超过 7.4、外圈挡肩孔径不小于 11.7；本版内圈接触件外 Ø7.2、内 Ø6.2，中央打印止肩孔 Ø11.8，避免接触防尘盖。见 [原厂轴承资料](https://www.nsk.com/content/dam/nsk/common/catalogs/ctrgPdf/bearings/e1103c_partc.pdf)及[归档的 C060/C061 安装尺寸表](source/NSK_686AZZ1_abutment_C060_C061.png)。

B 的内侧隔套为 7 mm，外侧只需 1 mm 内圈垫片。A 光轴长 23 mm，C 光轴长 29 mm，B 光轴长 36 mm，全部保留两端挡圈。A 使用 3 mm 铜套，C/B 使用 6 mm 铜套；CNC 座孔名义 Ø8.00、PETG 座孔名义 Ø8.05，均需按实际采购衬套确认装配配合。

要在共层布局中保留实际间隙，需要两处不同的避让：

1. **O 外侧：开口 C 形 OB 头。** A 中心半径为 35 mm，其相对 OB 的实际角度约为 −119.83°～−54.97°（腿长 225～120 mm）。OB 外头在左侧开口，为 OA 摇臂的整个扫掠区域让位；右侧头部与臂身保持为一个连续实体，两处右侧头部连接柱保留。A 轴内端在 Y=147.5，位于 OB 内板 Y=145 之外，因此内板保留完整 6 mm 厚度，无需轴端避让槽。
2. **C 外侧：取消围绕 B 的外叉环。** C 外帽只保留 C 端双剪支承和左侧两个 M3 连接位置 `(X,Z)=(-23,24)、(-23,46)`（相对 B）。B 周围的 CW 桥退到 Y=165，仅远离 B 的 C 螺钉柱接合面延伸到 Y=166，从而不给 OB 的 B 支承面留下摩擦贴面。

局部检查中 7 种杆件均为有效单实体。120、125、150、183.848、210、225 mm 六个姿态的零件检查，以及 120、183.848、225 mm 三个姿态的腿硬件对杆件检查，未发现超过 0.05 mm³ 的相交。两个主要共层间隙分别为 **OB 外板—OA 外耳 ≥1.5 mm**、**OB 外板—CW C 外帽 ≥1.227 mm**；CW 主件到 OB 外板留 1 mm。详见 [局部几何报告](leg_layout_review.json)。这些间隙数字来自上述有限姿态，不是任意姿态或受载挠曲的保证。完整 [整机运动检查](validation.json)覆盖 120～225 mm、每 5 mm 一次的 22 个姿态，包括已建模硬件之间的相交检查，未发现超过 0.05 mm³ 的相交。

[共层与 A/B/C 剖面图](previews/layout_shared_planes.svg) 展示了上述真实 Y 区间，便于区别“共用一层”与“向外叠加三层”。

## 6. 复用后的必要检查

1. O 端：OA 转子定位、螺钉可安装、OA 与两片 OB 及膝静壳全行程不相交；不能仅检查 A/B/C 剖面。
2. A、C：轴、衬套、内圈垫片、中央轴承舌均有明确轴向位置；紧固不通过压缩 PETG 来消除轴承游隙。
3. B：长隔套随总宽减小，不把原 V3 轴长和隔套直接沿用；光轴必须仍由两片完整 OB 支承。
4. 板面轮廓：曲线和圆角窗口服从运动间隙及孔边距；角点与叉根局部加厚，避免将装饰镂空穿过主要传力区。
5. 外观：尽量让 OB 两板、A/C 叉耳和连杆主面平行且连续，局部接口过渡用圆角或缓坡，避免整块连接座阶梯式向外堆叠。

以上是按参考图得到的结构拆解与复用逻辑。制造尺寸、实体检查和输出以同目录 V4 模型及验证报告为准。

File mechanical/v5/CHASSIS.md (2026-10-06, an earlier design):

# V5 中空机身与髋定子安装

本版本保留 200×150 mm 平面外廓，机身高度从 Z−50 到 Z85，共 135 mm。下部由五片 6061-T6 CNC 件承载；上部电子舱、顶盖、电池托盘和电子托盘采用 PETG。模型源为 `tools/cad_v5_chassis.py`，本文件不代替整机强度或散热验证。

## 分件与实际减重

| 文件内零件名 | 工艺/数量 | 结构与接口 |
|---|---|---|
| `chassis_lower_shell` | 6061-T6 CNC ×1 | 名称沿用，但实体是底板。Z−50..−47，四个电池安装柱延伸至 Z−39；非安装区内铣减至 2 mm 底厚 |
| `chassis_side_right/left` | 6061-T6 CNC 各1 | 3 mm 侧皮、上下整体安装梁；髋中心窗 Ø66、四孔 X/Z=±30。只有前后非髋区浅兜剩 1.5 mm；髋连接方框保留 3 mm |
| `chassis_front_wall/rear_wall` | 6061-T6 CNC 各1 | 3 mm 皮、完整角轨与电子托板支台；中部浅兜剩 1.5 mm，保留周边和支台背部 |
| `chassis_upper_shell` | PETG ×1 | Z47..82，3 mm 圆角空心壁，嵌入式 D435 窗口；上下独立紧固 |
| `chassis_lid` | PETG ×1 | Z82..85，可拆；Jetson 上方九条 76×4.8 mm 圆端槽 |
| `battery_tray` | PETG ×1 | 四孔 X±70/Y±20，安装面 Z−39；扎带槽，电池内腔平面 112×52 mm |
| `electronics_tray` | PETG ×1 | 188×108×3 mm，Z30..33；四孔 X±88/Y±45，与端墙金属支台连接 |
| `hip_stator_mount` | 6061-T6 CNC ×2 | 左右镜像；3 mm 中心环和 3 mm 外侧安装耳，单件加工 |

严格对照采用同一最终五片金属下壳，关闭或打开浅减重兜，统一按 2.70 g/cm³ 计算。原 964.016 g，现 793.044 g，减少 **170.972 g（17.74%）**。此数不含髋板、托盘、上舱、紧固件或电子件，不能充当整机质量。各件体积与前后质量在 [chassis_review.json](chassis_review.json) 的 `lightweight_metal_panels` 中。减重来自实际去料，不改变材料密度。

## 髋安装面及薄法兰通道

右髋定子安装面 Y72；中心环为 Y72..75、外 Ø62/内 Ø40.4。外耳为 Y75..78、78×78 mm 方板，中心通孔 Ø58，给外 Ø57 的电机连接杯保留名义 0.5 mm 单边径向间隙。两段是同一个 CNC 实体，在 Ø58..Ø62 环带连续相接。

髋定子六孔采用真实 J4310 的 PCD50、相位 30°+60°i，Ø3.4 通孔，外面 Y75 的 90° Ø6.4 沉头。使用 **DIN7991 M3×6，头 Ø6×1.7**，齐平面 Y75，穿板 3 mm、名义进电机螺纹 3 mm。不得直接换为更大头径的 ISO10642 M3。头部尺寸依据 [Böllhoff 原厂表](https://eshop-tr.boellhoff.com/out/media/pdf/DIN_7991_Stahl_10.9_gv___en.pdf)。购买时复核实际头型、长度与电机允许入牙深度。

四个机壳连接孔 X/Z=±30，Ø4.4；外面 Y78 的 90° Ø9 沉头，接 3 mm 侧墙。使用 **DIN7991 M4×12，头 Ø8×2.3**，配 0.8 mm 垫片和 3.2 mm M4 螺母。按模型的沉头面，头顶在 Y77.8、尖端在 Y65.8；螺母位于 Y68..71.2，名义露牙 2.2 mm。这是标准 12 mm 总长沉头螺钉，不是头下长 12 mm 的柱头螺钉。

现用电机杯 Y75.5 起，径向工具中心 Y79.5。耦合模块已检查真实两法兰、紧固件和四个 AF2 工具路径与髋安装件不相交；工具距实际安装板最小 0.5 mm。右髋原始电机 STEP 与本件/露出硬件的独立检查见 [chassis_motor_interface_validation.json](chassis_motor_interface_validation.json)。装入电机螺纹的杆段不在外露硬件 CAD 中重复建立；这些结果不是螺纹啮合分析。

## 电子件和相机接口

Jetson 托板上表面 Z33；整套主机采用最大包络 90.7 mm 沿 X、103.2 mm 沿 Y、高 35.86 mm。推荐放置 X−70.35..20.35、Y±51.6，顶部 Z68.86，至顶盖下表面 Z82 有 13.14 mm。尺寸来自项目归档的 NVIDIA 原厂完整机械图，不能使用单载板的 100×79×21 mm 尺寸替代。托板上的长槽是通用安装孔；整机电子支架另行定位，不声称通用孔与主机原厂孔系直接吻合。

D435 正面朝 +X，前面与 X100 平齐。上舱前壁矩形开口 Y−45.3..45.3、Z50.7..76.3，90.6×25.6 mm；采用完整矩形开口避免内圆角挤入相机最大矩形包络。四个支架通孔 Ø3.4 位于 **Y±50、Z56/72**，沿 X 贯穿。这四孔属于机身支架接口，不是 D435 本体孔位；相机支架和原厂后部 M3 限深由整机模块负责。

左右上舱各有两条 80×4.8 mm 圆端进气槽，中心 Z58/68；顶盖九条通风槽位于 Jetson 上方，间隔保留 5.2 mm 筋。通风孔避开螺母柱与相机，未给出风量、温升或防护等级承诺，须按最终功耗、风扇方向和布线实测。

电池托盘暂按 110×50×35 mm 长方体电池及扎带空间使用，实际电池外形、保护板和线头需根据选型复核；400 g 是整机负载假设，不是本托盘承载验证值。

## 螺钉采购与加工孔

下表数量覆盖两侧髋安装和整套机壳，不包括腿/轮机构、电子设备和相机支架。

| 位置 | 数量及规格 | 名义穿件/入牙 | 装配工具方向 |
|---|---|---|---|
| 底板→侧梁 | 8×DIN7991 M3×8 | 3 / 5 mm | 底面 |
| PETG 上舱→侧梁 | 8×M3×8 内六角柱头 | 3 / 5 mm | 上舱内部，设备装入前 |
| 顶盖→上舱 | 8×DIN7991 M3×10 + 8×M3 螺母厚2.4 | 夹持6.6 / 螺母2.4 mm，露牙1 mm | 顶部；螺母从上舱柱底放入 |
| 侧墙→端墙角轨 | 8×DIN7991 M3×8 | 3 / 5 mm | 左右外侧，髋组件装入前 |
| 电池托盘→底板柱 | 4×M3×8 内六角柱头 | 3 / 5 mm | 顶部开舱 |
| 电子托盘→端墙支台 | 4×M3×8 内六角柱头 | 3 / 5 mm | 顶部开舱 |
| 两髋板→两髋定子 | 12×DIN7991 M3×6 | 3 / 3 mm | 法兰杯装入前 |
| 两髋板→两侧墙 | 8×DIN7991 M4×12 + 8×M4 垫片厚0.8 + 8×M4 螺母厚3.2 | 夹持6.6 / 螺母3.2 mm | 外侧驱动，内侧持螺母 |

机壳部分为 40 颗 M3 螺钉和 8 颗 M3 螺母；髋安装另有 12 颗 M3、8 颗 M4、8 垫片和8螺母。原 PETG 热熔嵌件全部取消：金属件直接攻牙，PETG 顶盖使用可见的捕获螺母。

金属机壳 M3 孔在 STEP 中仅表示 **Ø2.5 底孔、6.5 mm 圆柱深、118° 钻尖另计约0.75 mm**；成品要求 M3×0.5 有效完整牙长至少5 mm，采用适合盲孔的丝锥并核查排屑。8 mm 高安装梁/柱底下保留约0.75 mm 名义余量。模型没有建立真实螺旋牙。盲孔加工深度与螺钉实际长度公差必须在加工图上分开标注。

浅兜平面内角 R3；安装梁、角轨及托板支台交界设置 R2，电池柱脚保留 R2 和 Ø20 不减薄地脚。建议底板用不小于11 mm 毛坯、侧墙14 mm、端墙18 mm 毛坯留夹持余量；多次装夹加工正背面孔，不要求从封闭机壳内加工。1.5 mm 余壁应安排合理加工顺序和支承，控制变形。PETG 孔径、公差和层方向须经试打，不能照搬 CNC 配合。

## 装配与验证边界

先连接侧墙与端墙，装底板；装左右髋电机/髋板并从内部固定螺母；装电池托盘和电池扎带；装电子托盘、设备与线束；将八颗顶盖螺母从上舱柱底放入，完成相机支架后固定上舱；最后封顶盖。上舱螺母柱入口朝下，必须在固定上舱之前放入螺母。保留所有电机线弯曲和连接器插拔空间，设备不可靠盖板挤压固定。

`chassis_review.json` 已完成十个单实体（九个固定件加一侧髋板）的几何有效性与内部相交检查，18个右髋硬件与髋板/右侧墙检查均通过，阈值0.001 mm³。最终电子包络及左右整机动态干涉由整机报告覆盖。当前 `chassis_hardware()` 不重复建立40颗机壳螺钉，只导出其确定的孔系和上表规格；髋安装硬件已建立。

这些验证确认零件几何与装配空间，**未验证跳跃冲击、板屈曲、紧固件疲劳或长期 PETG 变形**。最终跳跃能力必须以整机实际质量、姿态、落地载荷和专项强度验证为依据。

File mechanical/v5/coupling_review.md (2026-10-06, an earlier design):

# V5 紧凑髋膝连接法兰

两件结构保留：P1 连接髋转子，P2 连接膝后壳。总轴向跨度由 V4 的 21.8 降至 **14.9 mm**，缩短 6.9 mm；最大直径仍为 57 mm。每腿两件 CNC，全机四件。左右杯件不能直接翻面互换，使用各自 STEP。

文件：[截面及孔系 SVG](cnc/coupling_section.svg)、[PNG](cnc/coupling_section.png)、[局部 FreeCAD 装配](coupling_local_review.FCStd)、[几何报告](coupling_review.json)、[销及紧固件规格](coupling_fasteners.json)。

| 特征 | 最终尺寸／层面，mm |
|---|---|
| P1 前颈 | D39，Y72.2～75.5；定位口 D35.05×深0.8，贴合髋转子面Y73 |
| P1 套芯 | D43，Y75.5～82.5，套合长度7 |
| P2 杯件 | 外D57／套孔D43.05，Y75.5～87.1；底盘厚4.6 |
| 转子螺钉 | 6×ISO4762 M3×8，PCD27，相位0°；夹5、名义入牙3，头Y78～81 |
| 原厂定位销 | 3×D4×L9，PCD24.30，相位90°/210°/330°；入电机3、入法兰6，销底余肉3.5 |
| 膝后壳螺钉 | 4×NBK SLH-M3-6-SD，PCD38，相位45°；头Y82.6～84.6，铝承压2.5，名义入牙3.5 |
| 径向锁紧螺钉 | 4×NBK SLH-M3-8-SD，Y79.5，相位15°/105°/195°/285°；承压R26.3，头顶R28.3，名义入牙3.2 |
| 径向螺纹底孔 | D2.5圆柱深4.5，另留118°钻尖；加工完整M3×0.5螺纹至少3.5深 |

NBK 小头低头螺钉头径 D4.5±0.1、头高2、内六角2、8.8级。膝后壳 D4.8 沉孔完全落在 D43.05 套孔内，取消了 V4 杯壁上的四条轴向工具缺口。头径上限 D4.6 的包络也已检查。规格来自 [NBK 官方 SLH-SD 数据](https://www.nbk1560.com/images/en-US/product/lowsmallheadscrew/SLH-SD/SLH-SD_1.pdf)，已保存于本目录 `source/`。

小头会提高铝座承压，厂家列出的 1.4 N·m 仅是螺钉本体上限，不能直接作为此连接的锁紧扭矩。径向名义头下承压面积为 6.825 mm²，连接扭矩需按实际材料、预紧和负载确定。不得直接替换为普通高头螺钉。

装配顺序：先把带定位销的 P1 固定在髋转子；从杯口把 P2 固定到膝后壳；对孔套入7；最后均匀锁紧四颗径向螺钉。拆卸从径向螺钉开始。定位销法兰端固定、电机端可拆的配合需用实物孔确认，不将三根销默认设为电机端过盈。

几何检查通过：两个 CNC 件、17个硬件和双原厂电机无超过0.001 mm³的相交；14条真实六角工具路径畅通；沿轴线0～8 mm的六个套装位置均无相交。与 V5 实际髋板及其硬件无相交，四条侧向工具路径最小距板0.5。最小实测孔壁为转子沉孔至径向底孔1.652、定位销孔至转子沉孔1.866；杯口前唇1.6。图中的刀具至杯孔0.125径向间隙不是结构残留薄壁。

新电机层面：膝后壳Y87.1，整只电机平移Y132.6，前定子面Y132.1，转子面Y133.1。`tools/cad_v5_coupling.py` 的 `configure()` 返回这些基准且不修改全局参数；`designs(P)`、`hardware(P)` 供整机构建调用；`build(P, output_directory)` 生成局部审查包。完整销已在局部真实电机孔中检查，整机硬件略去进入刚体STEP转子的3 mm，以避免运动时静态转子孔引起假碰撞。

本版为制造审查原型；配合公差、实物装配、铝螺纹、预紧和疲劳承载仍需确认。

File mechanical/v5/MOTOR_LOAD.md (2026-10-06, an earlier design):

# V5 质量预算与电机负载初算

CAD 与设备资料合计约 **5.58 kg**；工程估计范围 5.38～5.88 kg。质量区间不是统计置信区间。

用户已确认采用 **J4310 24V、V1.1版本驱动**。采用实际130/35mm四杆和50mm轮半径；4310输出轴额定3、峰值7 N·m，额定120rpm、空载200rpm；H6215额定1、峰值2 N·m。不能再乘10:1减速比。本报告不采用48V型号的400rpm数据。

**平地低速运行具备初算可行性，跳跃能力尚不能确认。** 按CAD分布质量，183.85mm姿态每侧膝重力负载约 **1.96 N·m**，120mm低蹲约 **2.46 N·m**，均低于3N·m额定值，但低蹲控制余量较小。

另保留较粗的全质量集中筛查：标称姿态 **2.52 N·m**，低蹲 **3.16 N·m**。两列差异主要来自轮端非簧载质量和连杆分布重力，不能将简化列超过额定直接等同于实机必然失效。

首轮调试建议腿长约200mm、平地低速、加速度≤0.5m/s²，测实际电流与温升后再扩展范围；这是基于本次计算的调试起点，不是已验证控制限值。连续低蹲、快速平衡动作及跳跃需要额外余量。

## 质量组成

| 类别 | kg |
|---|---:|
| CNC | 2.145 |
| PETG | 0.307 |
| payload | 0.670 |
| motor | 1.920 |
| rubber | 0.144 |
| steel | 0.194 |
| allowance | 0.200 |

四台4310共1.20kg，两台H6215共0.72kg；Orin套件175g、D435按较新2025资料75g、电池400g、IMU暂20g。另留200g给线束、电源转换、接头、未建模紧固件及固定附件。PETG按实体体积计，实际切片和实称应替换预算。

## 站立和伸缩

| 腿长 mm | 膝转矩 N·m/侧 | 加25%余量 | 3N·m对应整机质量 kg |
|---:|---:|---:|---:|
| 120.00 | 3.16 | 3.95 | 5.30 |
| 160.00 | 2.80 | 3.51 | 5.97 |
| 183.85 | 2.52 | 3.14 | 6.65 |
| 200.00 | 2.27 | 2.84 | 7.36 |
| 225.00 | 1.78 | 2.23 | 9.39 |

### 按CAD分布质量复核

进一步把每件实体重心、机构运动归属和轮端质量分别计入重力势能，固定机身俯仰，轮心保持地面高度；左右电机虚功均分。电机总质量采用原厂值，电机内部重心用STEP均匀体积重心近似。该列比全质量集中更贴近当前几何，但仍不包含平衡控制和动态惯量。

| 腿长 mm | 髋重力转矩绝对值 N·m/侧 | 膝重力转矩绝对值 N·m/侧 |
|---:|---:|---:|
| 120.00 | 0.219 | 2.462 |
| 160.00 | 0.194 | 2.188 |
| 183.85 | 0.174 | 1.962 |
| 200.00 | 0.157 | 1.773 |
| 225.00 | 0.122 | 1.390 |

第一张表采用全质量集中等效；第二张CAD表已计入连杆分布重力与轮端非簧载质量，两表均未计转动惯量。只有重心对中、纯竖直的集中模型才给出髋支承力矩0；CAD分布自重、前后重心偏置、行驶反力矩和平衡纠偏都会要求髋输出。β=0也不自动满足整机静态平衡，实际姿态需让合力线通过支承点。

## 平地行驶

| 加速度 m/s² | 髋绝对和包络 N·m | 膝绝对和包络 N·m | 每轮 N·m |
|---:|---:|---:|---:|
| 0.0 | 0.13 | 2.59 | 0.027 |
| 0.5 | 0.45 | 2.79 | 0.097 |
| 1.0 | 0.78 | 2.99 | 0.167 |

采用标称腿长、滚阻系数0.02假设，表中把轮电机作用在CW上的反力矩按不利方向计入髋和膝。仍未包含轮转动惯量与姿态控制峰值。
120rpm对应轮缘速度约0.63m/s；320rpm对应约1.68m/s空载速度，后者不能当作满载运行保证。

| 坡度 | 每轮所需 N·m（滚阻0.02） | 最小切向附着系数近似 |
|---:|---:|---:|
| 5° | 0.147 | 0.107 |
| 10° | 0.265 | 0.196 |
| 15° | 0.381 | 0.288 |

坡度表仅为轮端牵引筛查；未将坡面切向力错误地直接代入全局水平雅可比。轮胎实测附着、整机重心、姿态控制和电机温升仍限制爬坡。

## 跳跃与落地

| 落差 m | 缓冲 mm | 平均载荷/重力 | 对应膝 N·m | B平均反力 N |
|---:|---:|---:|---:|---:|
| 0.05 | 30 | 2.67 | 6.28 | 240 |
| 0.05 | 50 | 2.00 | 5.26 | 192 |
| 0.05 | 80 | 1.62 | 4.80 | 177 |
| 0.10 | 30 | 4.33 | 10.20 | 391 |
| 0.10 | 50 | 3.00 | 7.89 | 288 |
| 0.10 | 80 | 2.25 | 6.64 | 245 |
| 0.20 | 30 | 7.67 | 18.04 | 691 |
| 0.20 | 50 | 5.00 | 13.16 | 480 |
| 0.20 | 80 | 3.50 | 10.34 | 381 |

按225mm开始缓冲、行程s结束时的力臂计算。**载荷是能量平衡得到的位移平均力；转矩是该力乘终点力臂，既非时间平均转矩，也非冲击峰值**。单腿先落地、结构弹性和控制延迟可进一步增大峰值。不得把表内低于7N·m视为已通过跳跃验证。
两侧膝电机若在120→225mm全行程始终提供7N·m，理想机械功上界约15.9J，对应扣除伸腿重力功后的理想抛升上界约0.18m。该数值忽略扭矩速度限制、峰值时间、转子与杆件动能和损耗，不能作为跳高预测。

| 理想离地后跳高 mm | 离地竖直速度 m/s | 膝电机相对转速 rpm |
|---:|---:|---:|
| 50 | 0.99 | 145.2 |
| 100 | 1.40 | 205.3 |
| 200 | 1.98 | 290.4 |

以上固定225mm腿长离地，β=0；膝电机转子相对定子的角速度是OA绝对角速度的两倍。100mm理想跳高已需要约205rpm，略高于24V型4310标称200rpm空载转速。50mm虽低于空载转速，所需转矩与145rpm能否同时达到仍无完整原厂曲线证明；改变离地姿态会改变该限制。因此当前电机组合尚不能确认满足跳跃目标。

## 公式与证据

`α=acos(ℓ/2L)`；`q_hip=−α`；`q_knee=2α−π`。轮心位置为`[L sin(qh)−L sin(qh+qk), −L cos(qh)+L cos(qh+qk)]`。β=0时雅可比两列为`(ℓ,0)`与`(ℓ/2,L sinα)`，已用独立中心差分核对。

- [完整数据与假设](motor_load_analysis.json)、[逐项质量](mass_budget.json)、[独立公式核对](motor_load_independent_review.md)、[结构初筛](STRUCTURAL_SCREENING.md)。
- [4310用户手册](../../references/DM-J4310-2EC/说明书/DM-J4310-2EC%20V1.1%20Geared%20Motor%20User%20Manual%20V1.2%202026-09-08.pdf)，第7页：300g、3/7N·m、120/200rpm。
- [H6215用户教程V2](../../references/DM-H6215/说明书/DM-H6215轮毂电机使用教程V2.pdf)，第1页：360g、1/2N·m、120/320rpm。
- [Orin官方机械规格](https://developer.nvidia.com/downloads/assets/embedded/secure/jetson/orin_nano/docs/jetson_orin_nano_devkit_carrier_board_specification_sp.pdf)，第29～30页：175g，整套103×90.5×34.77mm及公差。
- [D435官方2025资料](https://realsenseai.com/wp-content/uploads/2025/09/Intel-RealSense-D400-Series-Datasheet-October-2025.pdf)，第69、140页：75g与安装孔。

## 电源约束

四台4310在3N·m、120rpm与两台H6215在1N·m、120rpm的机械功率算术合计约176W，相当于24V母线至少7.3A，实际还需加驱动损耗、铜耗和电子设备功耗。该数值是指定六电机工作点的功率预算，不能作为本机器人常态耗电预测。静态保持机械功为0也仍有绕组发热。

4310手册的2.5/7.5A明确为额定/峰值相电流，不能直接把六台相电流相加当电池母线电流。400g仅给出了电池质量，电压、容量、放电倍率和BMS限流仍未知，因此本报告不能确认电源持续/峰值供电或续航。

本报告没有修改原MuJoCo惯量、控制器或热模型；旧仿真结果不构成本版实机能力证明。

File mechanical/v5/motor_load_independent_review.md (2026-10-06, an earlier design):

# V5电机负载独立复核

这是130/35mm四杆、轮半径50mm、4/5kg对称支承的集中质量筛查。它复核力学关系与数量级，不代表整机已通过跳跃或疲劳验证。详细场景与源文件校验值见[motor_load_independent_review.json](motor_load_independent_review.json)。

## 坐标、符号与轮反扭矩

`q_h=β−α`，`q_k=2α−π`，`α=acos(ℓ/2L)`。膝电机角度是转子相对膝定子的角度；OA绝对角度是`q_h+q_k`。工程髋/膝转轴为−Y，轮转轴为+Y。

`J_h=(−W_z,W_x)`，`J_k=(−L cos(q_h+q_k),−L sin(q_h+q_k))`。β=0时正好为`(ℓ,0)`与`(ℓ/2,L sinα)`。15组姿态与工程Geometry点位核对、中心差分、虚功和CW自由体力矩平衡均通过；中心差分最大误差 3.45e-11 m/rad。

令F为轮对腿施加的外力，+X向前、+Z向上。轮电机正向输出u_w时，CW承受的反力矩沿腿坐标为+u_w。静态保持指令为：

`u_h=−ℓ Fx−u_w`

`u_k=−(ℓ/2) Fx−L sinα Fz−u_w`

所以JᵀF是外载广义力，不能直接当同符号保持电机指令。正向牵引时轮反扭矩增加髋、膝需求；倒车/制动时必须按符号相加。采用轮心F+CW反力矩或地面接触点完整力旋量两种模型均可，但不能重复计入同一轮端力矩。虚功原理参考[Modern Robotics作者课程](https://modernrobotics.northwestern.edu/nu-gm-book-resource/5-2-statics-of-open-chains/)。

实际轮动力学还需`u_w=r F_ground,x+I_w ω̇+M_rr`；轮对腿的力为`F_ground+m_w g−m_w a_W`。下表把滚阻作为等效机身阻力并入Fx，只计一次，不再额外加第二个滚阻力矩。

## 竖直站立与正常行驶

| 腿长mm | 4kg膝N·m/侧 | 5kg膝N·m/侧 | 5kg AC张力N | 5kg B反力N |
|---:|---:|---:|---:|---:|
| 120.00 | 2.263 | 2.828 | 98.7 | 112.1 |
| 160.00 | 2.010 | 2.513 | 74.0 | 91.2 |
| 183.85 | 1.804 | 2.254 | 64.4 | 83.6 |
| 200.00 | 1.630 | 2.037 | 59.2 | 79.6 |
| 225.00 | 1.278 | 1.598 | 52.6 | 74.9 |

4310的3/7N·m分别为输出轴额定/峰值，不再乘10:1减速比。5kg低蹲120mm约2.83N·m，接近3N·m额定；不存在足够证据把剩余额定余量直接分配给纠偏和跳跃。纯竖直对中时髋理想力矩为0，但真实机身重心偏移、平衡纠偏、连杆重力和轮端反力矩均会改变它。

| 5kg、ℓ183.85mm、Crr=0.02 | 髋绝对值N·m | 膝绝对值N·m | 每轮N·m |
|---:|---:|---:|---:|
| a=0.0m/s² | 0.115 | 2.324 | 0.025 |
| a=0.5m/s² | 0.407 | 2.501 | 0.087 |
| a=1.0m/s² | 0.699 | 2.679 | 0.150 |

平地表采用`Fx=M(a+Crr g)/2`的显式工程预算。坡道单独以`τ_w=Mgr(sinθ+Crr cosθ)/2`筛查轮端，不把坡面切向力直接代入全局水平Fx。JSON含0/5/10/15°场景。

## 内力与跳跃边界

以AC受拉为正，β=0下完整自由体结果：

`T_AC=[L(sinα Fz+cosα Fx)+u_w]/[2R sinα cosα]`

`|B|=hypot(Fx+T sinα, Fz+T cosα)`

仅Fz存在时退化为`T=Fz L/(2R cosα)`。原竖直公式成立，但行驶和制动要保留Fx与轮反扭矩。V5每个A/B/C只有一只626轴承，不能将B反力再除以2。轴承目录静额定载荷不是可重复冲击的放行载荷。

落差h、缓冲行程s的`n=1+h/s`来自功—能平衡，是沿位移的平均法向力/重力；不是时间平均值，也不是峰值。按225mm开始压缩，在终点力臂上施加该平均力，只用于保守力臂筛查，并非真实平均电机转矩。

| 落差mm | 缓冲mm | 位移平均n | 4kg膝N·m/侧 | 5kg膝N·m/侧 |
|---:|---:|---:|---:|---:|
| 50 | 30 | 2.67 | 4.50 | 5.62 |
| 50 | 50 | 2.00 | 3.77 | 4.72 |
| 50 | 80 | 1.62 | 3.44 | 4.30 |
| 100 | 30 | 4.33 | 7.31 | 9.14 |
| 100 | 50 | 3.00 | 5.66 | 7.07 |
| 100 | 80 | 2.25 | 4.76 | 5.95 |
| 200 | 30 | 7.67 | 12.93 | 16.17 |
| 200 | 50 | 5.00 | 9.43 | 11.79 |
| 200 | 80 | 3.50 | 7.41 | 9.26 |

超过7N·m的平均力筛查场景已明显缺乏峰值余量；低于7N·m仍需要落地力曲线、完整扭矩—转速曲线和电流/热/结构验证。单腿先落地、偏载和执行延迟会放大局部峰值。

## 速度约束比理想能量上界更严格

β固定时`q̇_k=−ℓ̇/(L sinα)`，`q̇_h=ℓ̇/(2L sinα)`。下表按225mm处离地、抛升高度h计算所需速度；未假设电机能在该速度输出7N·m。

| 抛升高度mm | 离地速度m/s | 膝相对转速rpm | 髋转速rpm |
|---:|---:|---:|---:|
| 50 | 0.990 | 145.2 | 72.6 |
| 100 | 1.401 | 205.3 | 102.7 |
| 200 | 1.981 | 290.4 | 145.2 |

24V4310的空载上限为200rpm；225mm处离地达到100/200mm抛升所需的205/291rpm已经达到或超过该标称空载上限。50mm情形约145rpm虽低于空载值，也不能据此保证负载下有足够转矩。改变离地腿长会改变速度力臂；例如200mm处离地的需求另列于JSON。

- 4kg：两膝若在120→225mm始终7N·m，理论功15.85J；扣除重力功后抛升上界0.299m。该条件没有厂商完整峰值曲线支持，不能当跳高预测。
- 5kg：两膝若在120→225mm始终7N·m，理论功15.85J；扣除重力功后抛升上界0.218m。该条件没有厂商完整峰值曲线支持，不能当跳高预测。

## 必须补入完整模型的项

- 使用V5实际各零件/设备质量、质心与惯量；轮端非簧载重量和连杆自重逐项建模，避免与全质量集中于髋的近似重力重复计算。
- 机身俯仰/横滚、重心相对O的偏置、左右不等载荷、惯性和离地/着地接触时序。髋驱动反作用直接影响机身平衡。
- 电池电压降、驱动电流和母线功率、峰值持续时间、绕组温升、轮胎刚度/阻尼、间隙和制动回馈。
- 当前balance_control通过MuJoCo完整耦合模型求平衡，物理上包含轮反作用；旧几何/估算惯量和控制限幅不证明V5实机能力。

## 原始证据

- [工程Geometry](../../wheel_leg/geometry.py)、[MJCF转轴](../../wheel_leg/build_model.py)、[平衡控制](../../wheel_leg/balance_control.py)；相关文件SHA256已写JSON。
- [J4310原手册第7页截图](source/j4310_specs.png)：24V、3/7N·m、120/200rpm、约300g。
- [H6215原手册第12页截图](source/h6215_specs.png)：1/2N·m、120/320rpm、约360g。motor_specs.py中“手册没有提供”的旧注释与原页不一致，本复核以原页为准。
- 原厂V1.1曲线只显示约120rpm、0～4.5N·m附近的测试，未提供可据以保证7N·m全速度输出的完整包络。

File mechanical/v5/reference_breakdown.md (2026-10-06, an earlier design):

# V5 参考图拆解：完整 OB 包裹 OA，CW 改一体叉

本文件先拆参考图，再复用到本机。现已实现 **22 mm 的完整 OB 包裹式结构**，并完成本地六姿态几何检查；这不是已验证的跳跃承载结构。全部关键承载件采用铝合金 CNC；保留 OB=AC=BW=130 mm、OA=BC=35 mm。原图见[归档参考图](source/reference_mechanism.png)，示意重绘见[独立拆件与轴向图](previews/reference_breakdown.svg)，最终实体关系见[FreeCAD 实体剖面](previews/joint_sections.svg)。

## 1. 先按参考图分离各个运动实体

| 实体 | 图中或用户明确的信息 | 不能由渲染图确定的信息 |
|---|---|---|
| OB 内板 | 用户明确是一片从 O 到 B 的完整板 | 板厚、内表面台阶、销孔、公差 |
| OB 外板 | 与内板平行，同样从 O 连续到 B；共同夹住 B 处 CW | 隐藏螺钉、隔柱、原图内部具体制造分界 |
| OA 短曲柄 | 紫色，O 为驱动中心，A 为与 AC 的转动连接；位于 OB 结构包围的区域 | 一体加工还是拼合叉、隐藏支撑与材料 |
| AC 长杆 | 红色，A 和 C 两个圆头，进入 OA/CW 对应叉口 | 轴承数量、压配、外圈和销轴防脱 |
| CW 下杆 | 青色，C、B、W 属同一运动刚体；B 舌嵌入 OB，C 叉夹 AC | 原件是否一体 CNC、背面筋、叉槽刀具方向 |
| 两个俯仰执行器 | 髋输出带膝静壳和 OB；膝输出带 OA | 原型号、真实安装孔、定位销尺寸 |
| 足盖和足端 | 粉色盖与黑色足端是独立件 | 本机替换为 H6215 和轮圈，不复刻 |
| 髋横滚执行器/支架 | 图中右端一组；用户已要求删除 | 本机不复用 |

黄色和灰色圆环有遮挡，不能仅按颜色断言每个圈都是独立法兰或轴承。实际髋/膝安装以用户 DM-J4310-2EC STEP 和二维图为依据。图中看不清的制造分缝，不作为事实补画。

## 2. 复用时保留五个主要腿部制造件

1. **OB 内框板**：整片 O→B，含膝静壳接口和 B 内侧支撑；内侧局部台阶可增加 B 轴承载长度。
2. **OB 外盖板**：整片 O→B，覆盖 OA。允许小工具孔和非承载观察窗，不开 V4 那种使 OA 与 OB 并排的大扇形缺口。
3. **OA 一体 CNC U 叉曲柄**：两个 A 耳和 O 端驱动座连成一个实体；全部放入两片 OB 之间。O 端留真实转子孔系和定位杯，空腔减重不割断传扭路径。
4. **AC 单杆**：两端装轴承，杆身连续；端部的薄保持片属于轴承防脱小件。
5. **CW 一体 CNC 下杆**：C 的两耳和背桥直接加工在本体上，B 为中间轴承舌，W 为轮电机接口。删除独立 C 外帽、两根外伸 M3 螺钉柱及相应分支。

OA/CW 一体 U 叉是本机针对 CNC 的新制造方案，不宣称原图必然采用同样分件。叉背必须放在 AC 实际扫掠的背侧，使用连续圆弧桥与杆身相接；不能把原 V4 外叉螺钉柱简单融合后继续保留为冗余凸块。

## 3. OB 包裹 OA 的最终 22 mm 层面

以膝前定子安装面 **S = `knee_stator_face_y`** 为轴向基准，实际 S=132.1 mm；包络为 Y=132.1～154.1 mm。

| 元素 | 相对 S 的 Y 区间 / mm | 作用 |
|---|---:|---|
| OB 完整内板 | 0～3 | 完整承载框与电机安装面 |
| OA / CW 内叉耳 | 3.5～6.5 | 各 3 mm，与 OB 内板间留 0.5 |
| AC 两端及 CW 的 B 舌 | 7～15 | 给轴承、止肩、保持片预留 8 mm |
| OA / CW 外叉耳 | 15.5～18.5 | 各 3 mm，均位于 OB 内腔 |
| OB 完整外盖板 | 19～22 | 完整覆盖，距叉耳外面留 0.5 |

与 V4 共层设计的区别是：**OB 外盖位于 OA 外耳之外，OA 被两片 OB 包裹。** B 的 OB 两侧支撑可做向内的局部台阶，靠近 B 轴承，避免用长轴跨过整个空腔承弯；这些凸台只在 B 附近，不把整块板向内加厚。

正面两片 OB 采用 R50.5 的完整圆弧头部覆盖 R35 的 A 端摆动区域，均连续到 B，不设大扇区缺口。OA 的 O 端桥为局部连续结构，外端到 S+18.6，与外盖间保留 0.4 mm。A 两耳为 3 mm；不是把整个短曲柄做成实心厚板。

## 4. 轴承与轴向固定：不省略隐藏结构

考虑用户需要跳跃，本版采用每处 **单颗 NSK 626ZZ1（6×19×6）**。双剪来自金属轴在两个耳内支撑，并不要求轴承数量必须为两颗。其静额定载荷相较 686AZZ1 更高，但额定载荷不能直接作为机器人可跳跃证明；整机质量、短腿机械增益、冲击、轴弯曲和疲劳由专项校核确定。

最终轴承轴向位置为 S+7.75～13.75；一体外圈止肩为 S+7～7.75。外保持片约厚 0.8，放在 S+13.8～14.6，名义留 0.05 mm 外圈轴向装配间隙；三颗超薄 M2 头占 S+14.6～15.1，仍位于外叉耳 S+15.5 以内。保持片采用外 Ø28、内 Ø16.8，三孔 PCD24；AC 端眼半径取 15.5 mm，给 M2 头和孔边保留材料。保持片在槽外预装，避免叉耳遮挡 M2 装配工具。

626ZZ1 安装肩部按 NSK 表：内圈接触件外径不超过 8.5，外圈肩孔不小于 16.5。本版用内圈接触件外 Ø8.4、内 Ø6.2，外圈肩/保持片内孔 Ø16.8，防止碰到防尘盖。数据来源：[NSK 原厂目录 C060/C061](https://www.nsk.com/content/dam/nsk/common/catalogs/ctrgPdf/bearings/e1103c_partc.pdf)。

A/C 轴端不能伸到 OB 板内。本版使用 Ø6 钢轴、两端内 M2 螺纹，配外 Ø9、内 Ø2.2、厚 0.2 的钢保持垫片和 NBK SETS-M2-4 超薄头螺钉。原厂给出的头径 4、头厚 0.5，需配专用 T4 工具：[NBK SETS-M2](https://www.nbk1560.com/en/products/specialscrew/nedzicom/lowsmallheadscrew/SETS/SETS-M2/)。耳外面各留 0.5 mm 深、Ø9.2 沉台后，铜套支撑长约 2.5 mm；钢轴名义跨 S+4～18.05，长 14.05 mm。轴端硬件包络 S+3.3～18.75，对 OB 内/外板分别留 0.30/0.25 mm。垫片 Ø9 必须超过铜套 Ø8，搭在铝耳上形成真实防脱，而非仅靠铜套摩擦。

这类 M2 仅用于轴向保持，主要径向剪切由 Ø6 钢轴及两耳承担。轴端长度需留明确轴向游隙，不能靠拧紧薄头螺钉压出轴承预载。薄垫、螺钉松动和跳跃侧向冲击仍需验证；如果端面空间不足，应增加总宽或改保持结构，不默许零间隙。

## 5. 装配与加工顺序

1. 在 AC 两端和 CW 的 B 眼装单 626、内圈接触隔套、钢外保持片及三颗 M2；保持片必须先在叉口外锁好。外圈座按 Ø19 H7 加工并核对实物，不靠默认压配代替机械防脱。
2. 在框外把 AC 的 A 舌插入 OA 一体叉，装两个铜套、Ø6 短轴及两端垫片/T4 低头螺钉；C 同样在框外组好。**OA 已进 OB 内框后，A 内侧 T4 被完整内板遮挡，不能声称两面仍可直接操作。**
3. 将 OA+AC+CW 子机构沿 Y 放入 OB 内框，定位杯对准真实膝转子；从外侧锁六颗 M3×16。沉孔底 S+13、转子面 S+1，夹持 12 mm、入牙 4 mm，原电机 5 mm 盲孔留 1 mm 底隙。
4. 装 B 轴和内侧保持件，外盖的铜套对准 B 轴，沿 Y 合拢外盖。四颗沉头 M3×8 将外盖锁入内框一体连接柱；B 两端保持件通过 Ø9.2 沉台从两面操作。外盖中央只有 Ø12 小孔，六颗转子螺钉不通过此孔安装。
5. W 端采用 H6215 真实孔系：3×M3、PCD17.5，面 S+15。M3×8 的头下底面为 S+10，5 mm 夹持、3 mm 入牙。W 中央保持实心，保留电机自身的径向侧出线口；不把 Ø12.9 内凹腔误当成要求贯穿连杆的凸台。

OA/CW 的双耳间隙沿 Y 为 9 mm，并向 A/C 的开口侧敞开。加工需要双面装夹，叉槽用侧铣或合适直径的槽铣刀从开口加工；B 的圆环桥内侧可通过 B 轴向通孔进刀，连续圆环不能留为封闭、无法进刀的内腔。轴向台阶与孔同轴度必须保证；实物 CAM 应按刀具半径设置槽根圆角，不允许用本模型的理想锐边要求制造无限小刀尖。曲线轮廓与三角窗口已有圆弧/曲线过渡。此处说明可选装夹路径，不等于已生成刀路或完成加工厂评审。

## 6. 几何与截面证据

- 5 个主要 CNC 制造件全部通过 FreeCAD BREP 校验，均为单实体；本地腿长 120、125、150、183.848、210、225 mm 的主件检查，以及端点/名义位腿硬件检查，无超过 0.05 mm³ 的相交。
- OA 对完整 OB 内板最小间隙 0.5 mm、对外盖最小 0.4 mm；AC 对 OA/CW 叉耳为 0.5 mm。B 的两板连接柱端面接触是固定连接，不算运动干涉。
- 独立[真实电机与 OA 审查](OA_interface_independent_review.json)验证 26 个真实电机实体及六条 AF2.5 工具路径。OA 沉孔到桥外缘最薄 2.1 mm、到 Ø12 中孔 4.6 mm；这些仅是几何余肉，不是扭矩/疲劳合格证明。
- [截面审查](leg_layout_review.json)记录保守连续纵肋：AC 8×12.4 mm；OB 每板每侧 3×7.16 mm；CW 每侧 8×6.14 mm。后两者是三角镂空板的边肋，不能以整个板外轮廓当作实心截面。保守压杆初筛按 130 mm 无外部侧向支撑长，未将斜肋或连接柱当作固定支点。
- W 中央已恢复 8 mm 实体，三颗 M3 的头下承压环均实测为 100% 完整。原电机侧开口宽 6.5、轴向深 3.75，装后位于 Y=147.1～150.85，在 CW 安装面之外；6.4×3.65×18 mm 的径向净空探针与真实 STEP、新 CW 均无相交，见[轮端侧出线审查](H6215_W_interface_review.json)。线束直径、连接器外廓和弯曲半径没有尺寸资料，探针仅证明厂家侧口保持畅通，不是线束装配或最小转弯验证。
- 全机离散姿态检查、近似质量和载荷评估以同目录的整机报告为准。离散检查不能保证所有连续姿态；跳跃冲击、局部屈曲、孔边疲劳和轴向松动仍需专项验证。

所有结果写入 V5，未覆盖 V4。

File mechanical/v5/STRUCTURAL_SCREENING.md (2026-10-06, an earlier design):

# V5结构初筛：轴压屈曲与销轴弯曲

质量读取本版mass_budget.json：名义5.5797kg，预算区间5.3797～5.8797kg。区间不是统计置信区间。以下仅计算1g/3g对称支承、腿长120～225mm的理想柱屈曲和销轴名义弯曲。**轮端W及其他孔边局部强度仍未完成验证，不能据此批准跳跃或加工放行。**

材料暂取6061-T6，弹性模量采用[Kaiser官方6061资料第2页](https://online.kaiseraluminum.com/depot/PublicProductInformation/Document/1006/Kaiser_Aluminum_Shapes_Soft_Alloy.pdf)的典型值68.3GPa；它不是本批材料保证值。6061材质/热处理状态及钢销材料证书待确认，本报告没有指定许用应力。

## 实际截面与屈曲假设

截面来自cad_v5_leg.beam_sections及leg_layout_review.json，沿板中厚度每0.2mm与CAD求交；宽度向下取整。该采样不是严格连续最小值。每条边梁都按130mm无侧向支承、两端铰接K=1处理，不把三角筋或连接柱默认视为理想横向支承。

`I_min=min(w t³,t w³)/12`；`P_cr=π² E I_min/(K L)²`。

| 部位 | 每条截面mm | 条数 | I_min每条mm⁴ | 细长比 | P_cr每条N | 均分时条件合计N |
|---|---:|---:|---:|---:|---:|---:|
| OB | 3×7.16 | 4 | 16.11 | 150.1 | 643 | 2570 |
| AC | 8×12.4 | 1 | 529.07 | 56.3 | 21103 | 21103 |
| CW_BW | 8×6.14 | 2 | 154.32 | 73.3 | 6155 | 12311 |

这里的合计值要求各条同时均匀受压且变形协调；不能将OB四条梁的P_cr简单相加后视为已验证的整件承载力。边梁弯曲、曲率、偏心、连接刚度和加工误差都没有进入该理想公式。

## 1g/3g载荷与敏感性

定义`Fz=nMg/2`；n=1表示静态法向支承，n=3表示总法向载荷为3Mg（集中质量模型对应向上加速度2g）。3g是指定筛查工况，不是实际落地峰值。

`T_AC=Fz L/(2R cosα)`，`B=hypot(T sinα,T cosα+Fz)`，`α=acos(ℓ/(2L))`。OB轴压分量为`T+Fz cosα`，这里用更大的B作为轴压敏感性载荷；CW的BW下段轴压为`Fz cosα`，用Fz作轴压敏感性载荷。**同时存在的弯曲并未因此消失。AC在这两个工况受拉，Euler仅表示反向受压假设，不能解释其真实受拉强度。**

| 总法向载荷 | AC张力范围N | B反力范围N | OB单条承担全部B的最小P_cr/P | OB四条均分最小P_cr/P |
|---|---:|---:|---:|---:|
| 1Mg | 56.6～116.0 | 80.6～131.9 | 4.87 | 19.49 |
| 3Mg | 169.9～348.1 | 241.7～395.6 | 1.62 | 6.50 |

范围包含质量预算上下限和120～225mm腿长。P_cr/P是理想柱临界载荷与指定轴压的比值，**不是结构安全系数**。单条全载与四条均分只是负载分配敏感性两端，不证明实际分配落在其间，也不包含弯矩下的一侧拉、一侧压。完整逐姿态AC/CW比值见JSON。

## D6中空端部销轴

每个销轴总长14.05mm；相对膝前定子平面S，销轴为S+4～18.05。铜套接触带S+4～6.5、S+15.5～18，支承中心S+5.25、S+16.75，间距11.5mm。单只626轴承载荷中心S+10.75，左右力臂a=5.5、b=6.0mm。

`M_max=Pab/(a+b)=2.8696P N·mm`；`σ_b=32M_max/(πd³)`，d=6mm。为观察支承接触位置不确定性，另取支承反力在铜套最外缘S+4/18、点载位于跨中，得到包络`M≤3.5P`；这只涵盖接触位置移动，没有涵盖冲击载荷大小误差。

| 总法向载荷 | B销名义/接触位置包络弯曲应力范围MPa |
|---|---:|
| 1Mg | 10.90～21.76 |
| 3Mg | 32.70～65.29 |

表内低端使用预算下限/长腿/支承中心，高端使用预算上限/短腿/接触位置包络。A/C销载荷为T，B销载荷为B；全部分项见JSON。没有钢种、热处理和疲劳依据，因此不把这些名义应力转换成“通过”结论。

CAD的M2两端孔为Ø1.6平底简化孔，止于S+8.2和始于S+13.75；中间净实心段为**5.55mm**，最大弯矩位置S+10.75落在实心段。若保持当前圆柱钻孔深度，另补118°钻尖，每端尖长0.481mm，净实心段约**4.589mm**，仍覆盖载荷中心。

当前五金规格要求每端≥4mm完整M2螺纹、名义入牙3.8mm。CAD的平底Ø1.6孔不能代替完整钻孔/攻牙工艺：钻尖、底攻退刀余量、实际总深度及保持中央实心区必须在加工图中限定。螺纹根部、过渡孔底、接触压力和微动疲劳未计算。

## 尚不能说明的事项

- CW承受弯曲和轮电机反扭矩；W孔边、轴承座、OA/OB孔边、螺纹剥离、扭转及应力集中不能用Euler结果代替。本报告不表示这些局部强度已完成验证。
- 1g/3g均为左右对称载荷。单腿先着地、侧向冲击和真实力—时间曲线可超出该范围。
- 不包含曲梁屈曲、残余应力、装配偏心、连接滑移、疲劳或FEA。铝合金典型E和钢销名义应力不等于材料证书及设计许用值。
- [完整计算与输入快照](STRUCTURAL_SCREENING.json)、[质量预算](mass_budget.json)、[CAD截面来源](leg_layout_review.json)。源文件SHA256保存在JSON；几何或质量改变后应重算。

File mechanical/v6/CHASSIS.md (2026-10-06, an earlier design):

# V6 连续曲面中空机身与内部装配

坐标：X 向前、Y 向右、Z 向上，髋轴为原点；尺寸单位 mm。整高曲面机身由前主壳和大后盖组成，在 X−20 沿竖向分件。D435 位于连续前面板，内部重新布置了金属骨架、主机托盘和低位电池。不存在独立上舱、水平叠舱或顶部相机头。

## 结构和分件

| 分件 | 材料与功能 |
|---|---|
| 腹部底板、左右髋承力框、前后横框，共 5 件 | 6061-T6 CNC。髋座载荷通过侧框、上下边梁和横框传到另一侧及底板；这是腿部的主要承力通道。 |
| 前主壳、大后盖，共 2 件 | PETG、名义壁厚约 3。外轮廓从 Z−52 连续延伸到 Z82，以圆角截面平滑放样，包住整个金属框及电子设备。 |
| 左右肩罩，共 2 件 | PETG、弧面内 R33/外 R36，轴向 Y±78.2..±130。半包膝电机上方，与机身侧腹相接，底部开放。 |
| 电池托盘、电子托盘、Jetson 左右夹条，共 4 件 | PETG，承担设备固定；不作为腿部主承力结构。 |

机身模块共 13 个主件：5 件 CNC、8 件 PETG。相机 PETG 支架由独立 payload 模块提供，髋座和电机接口另计。原生 CAD 中这些零件分别保留，装配 STL 不替代各制造零件。

前壳约 124×172×134，后盖约 90×172×134；左右肩罩每件约 107×51.8×38.5。主壳曲面外缘 X≤100，后部 X≥−110；侧面局部紧固座至 Y±86。前后壳分缝具有 4 mm 伸入深度的内部曲面导向舌，接收口名义留 0.3 间隙。导向舌只帮助对位，真正紧固由前后金属横框承担。

侧面保留 D72.4 电机穿孔，并在内侧给髋座方形耳板作 X/Z±39.5、|Y|74.9..78.5 的浅凹口。外曲面保留，不能把金属髋座强行压入塑料壳。肩罩底部 Z5 以下开放，距膝前定子基准 Y132.1 留 2.1 轴向间距。

## 相机与主机

D435 前面位于 X100、中心 Z19，整机前窗 Y±45.3、Z6.2..31.8，开口为 90.6×25.6。四个前安装点 Y±50、Z11.5/27.5，前壳设置 X97..100 的实体座；相机支架臂前端 X97 与该座实际接触；四个臂端有 8.4×8.4 的局部内兜，修平到 X97，避免曲面内壁与臂的方角相交。前金属横框有 116×70 的贯通开口，同时避让相机本体、四条后支架臂和背部横梁。

相机资料有两种深度：本次官方 ROS 网格安装深度约 25.05；较新尺寸图为 26.05。当前装配以 1.0 金属垫片配合 M3×6 固定网格版本；26.05 实物应移除垫片、改 M3×5。最终以实物安装面和有效螺纹深度核对，详见 payload 接口文件。

Jetson 使用官方完整开发套件 STEP，保留原厂底座、载板、模组、散热器及风扇。真实底座最低实体面 Z33 与托盘上面接触，最高处约 Z67.766；B-spline 控制包围盒低于 Z33 不代表实物穿透。设备约占 X−70.526..20.526、Y±51.690，顶面到壳内面约 11 mm，壳顶部与侧面开通风槽。

电子托盘缩到 X−86..66、Y±54、Z30..33，给低位相机及后方螺钉留空。四个框架支承位于 X−74/+38、Y±48，上表面 Z30；托盘在这些台阶上实际承压。Jetson 两条外围夹条通过 X−78/+38、Y±38 的独立四孔锁紧，不借用已被原厂底座占用的载板安装孔，也不夹 PCB。夹条防抬唇与原底座上边缘有 0.5 名义间隙；四个方向止挡限制平移。

电池暂为 400 g 长方体，放在低位托盘；托盘底部四槽用于穿两条宽度不超过 10 mm 的绑带，必须加绑带限制电池上抬，绑带未建模。IMU 仍为占位包络。主机接头面前方预留空间，但实际 USB、电源线接头及弯曲半径尚未确定，不把空腔尺寸等同于线束验证。

## 固定链与紧固件

| 固定位置 | 规格 / 数量 | 实际夹持关系 |
|---|---|---|
| 底板到侧框下梁 | DIN7991 M3×8，8 颗 | 底板 3；侧梁入牙 5。底板顶 Z−47 与侧梁底 Z−47 接触。 |
| 侧框到前后横框 | DIN7991 M3×8，8 颗 | 侧框 3；横框边条入牙 5。先从侧面锁紧，再装外壳。 |
| 电池托盘到腹板支柱 | M3×8，4 颗 | 托盘 3、入牙 5。 |
| 电子托盘到侧框棚架 | M3×8，4 颗 | 托盘 3、入牙 5；四处台阶顶 Z30。 |
| 前主壳到前横框 | M3×20，4 颗 | 头下 X100；PETG 柱至金属接触面 X86，夹持 14、金属入牙 6。孔位 Y±62/Z−40、41。 |
| 大后盖到后横框 | M3×30，4 颗 | 头下 X−110；接触面 X−86，夹持 24、金属入牙 6。 |
| 肩罩到侧框实体凸台 | M3×20，4 颗 | 肩罩座 Y绝对值89、壳体接触面 86、金属接触面 75；夹持 14、金属入牙 6。孔位 X±45/Z35。 |
| Jetson 外围夹条 | M3×10、垫片 0.5、M3 螺母 2.4，各 4 | 夹条 3＋托盘 3、垫片 0.5、螺母 2.4，末端露 1.1。 |

上述外罩与主机共 16 颗螺钉、4 片垫片、4 颗螺母，24 件硬件已建模。金属框和托盘的另 24 颗螺钉仅列采购规格，没有重复实体。髋座 M3/M4 硬件由髋模块提供；模型中的入牙段按各接口注释省略，不能据可见杆长采购短螺钉。

前托盘棚架在 X30/Z30 处作 D11 沿 Y 的局部凹口，避让髋座上前 M4 垫片、螺母及薄壁套筒。髋座螺母使用 AF7、外径不超过 10 的保持工具，在电子托盘安装前操作；侧框 3 mm 承压皮层保留。前后横框侧轨加厚到 5 mm，并与 3 mm 端面皮层连成 8 mm 截面；侧向 M3 孔心距 X 向内外边各 4 mm，D2.5 底孔最小余肉 2.75 mm。为避让加厚侧轨，上下纵梁端部退至 X±77.5，后托盘棚架起点也退至 X−77.5，与侧轨留 0.5 间隙；底板原 X±70 孔及托盘 X−74 孔保留。前后壳接收孔保持贯通，避免轨加厚后形成过浅盲孔。

## 装配与维修

1. 装配金属内框和髋座，完成髋座 M4 螺母锁紧；其工具入口随后会被电子托盘遮挡。安装电池、托盘、Jetson 和夹条，核对实际底座承压及防抬间隙。
2. D435、后 PETG 支架、金属垫片和相机紧固件先装在前主壳上，形成一个可拆前部模块。前壳沿 X 方向套到内框，支架通过前横框开口；不要先把相机固定到内框再强套外壳。
3. 完成前壳紧固后再装外部髋膝耦合件、膝电机和腿部。髋膝总成已装好时不得凭静态无干涉结论强行套入前壳。
4. 大后盖从后方沿 +X 推入，导向舌对位后锁紧四颗 M3×30。最后安装两侧肩罩。维护时先拆肩罩，再向 −X 抽出后盖；前壳、相机和腿部可留在机身上。拆下后盖并不意味着整盘主机能够直接从后横框中抽出：横框开口上缘只有 Z35，Jetson 顶部约 Z67.766。

主机连同托盘、夹条及夹条的 12 件硬件一起取出时，按下列顺序操作：

1. 断电、断开主机相关线束，将机体支稳并使腿部卸载；拆下两侧肩罩和后盖。
2. 卸下电子托盘的 4 颗 M3×8，扶住托盘，暂让其仍落在侧框承台上。
3. 扶住后横框，卸下其两侧共 4 颗 DIN7991 M3×8，先把后横框沿 −X 退出。
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

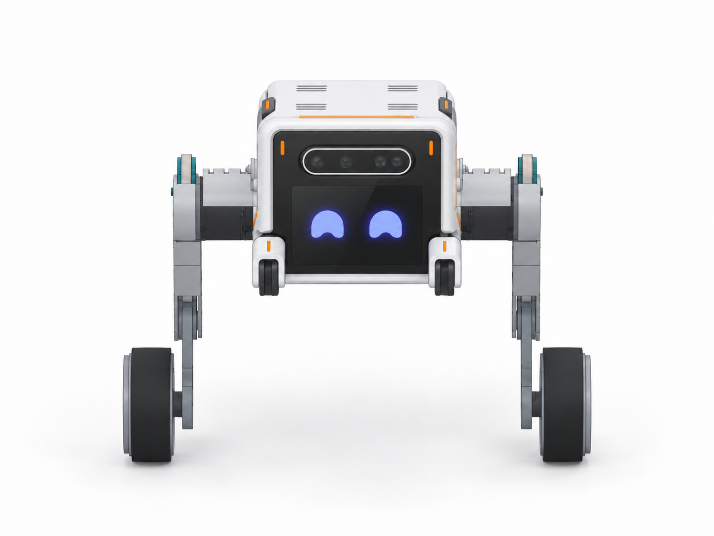
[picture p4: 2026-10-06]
mechanical/v8_3/source/wheel_leg_front.png

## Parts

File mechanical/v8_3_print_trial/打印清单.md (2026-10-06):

# V8.3 打印试装清单

共 **38 种、77 件**定制零件。每种只提供一个STL；文件名`_x02`表示打印2件。左右不同件已分开编号，禁止自行镜像代替。

全部STL均为毫米、100%名义尺寸，已摆到Z=0；不是预切片G-code。下列参数是试装起点，支撑仍须在切片器中检查。

|编号|名称|单机数量|模块|摆放后X×Y×Z mm|层高/首层 mm|周壁/填充|STL|
|---|---|---:|---|---|---|---|---|
|P01|机架底板|1|M03|174.00×144.00×11.00|0.16/0.2|4道/30%|[下载](STL/03_chassis/P01_chassis_belly_plate_x01.stl)|
|P02|右承力侧框|1|M03|172.00×94.00×32.00|0.16/0.2|4道/30%|[下载](STL/03_chassis/P02_chassis_hip_frame_right_x01.stl)|
|P03|左承力侧框|1|M03|172.00×94.00×32.00|0.16/0.2|4道/30%|[下载](STL/03_chassis/P03_chassis_hip_frame_left_x01.stl)|
|P04|前后通用横框|2|M03|94.00×144.00×8.00|0.16/0.2|4道/30%|[下载](STL/03_chassis/P04_chassis_front_crossframe_x02.stl)|
|P05|前主壳|1|M06|161.00×208.00×193.00|0.2/0.2|4道/20%|[下载](STL/06_shell/P05_chassis_front_shell_x01.stl)|
|P06|后检修壳|1|M06|154.49×172.00×74.00|0.2/0.2|4道/20%|[下载](STL/06_shell/P06_chassis_rear_cover_x01.stl)|
|P07|屏幕相机前脸板|1|M05|144.00×148.00×4.40|0.2/0.2|4道/20%|[下载](STL/05_front_face/P07_display_front_bezel_x01.stl)|
|P08|左右通用肩罩|2|M06|107.00×51.80×38.50|0.2/0.2|4道/20%|[下载](STL/06_shell/P08_shoulder_fairing_right_x02.stl)|
|P09|电池托|1|M04|154.00×54.00×14.40|0.16/0.2|4道/30%|[下载](STL/04_electronics_bay/P09_battery_tray_x01.stl)|
|P10|电器托盘|1|M04|152.00×108.00×3.00|0.16/0.2|4道/30%|[下载](STL/04_electronics_bay/P10_electronics_tray_x01.stl)|
|P11|Jetson右夹座|1|M04|125.50×9.40×22.20|0.16/0.2|4道/30%|[下载](STL/04_electronics_bay/P11_Jetson_base_retainer_right_x01.stl)|
|P12|Jetson左夹座|1|M04|125.50×9.40×22.20|0.16/0.2|4道/30%|[下载](STL/04_electronics_bay/P12_Jetson_base_retainer_left_x01.stl)|
|P13|D435一体后座|1|M05|24.00×108.00×28.05|0.16/0.2|4道/30%|[下载](STL/05_front_face/P13_D435_embedded_bracket_x01.stl)|
|P14|IMU刚性安装桥|1|M04|36.00×143.00×32.00|0.16/0.2|4道/30%|[下载](STL/04_electronics_bay/P14_HI13R2_rigid_bridge_x01.stl)|
|P15|屏幕右托夹|1|M05|81.50×16.00×17.50|0.16/0.2|4道/30%|[下载](STL/05_front_face/P15_display_case_cradle_right_x01.stl)|
|P16|屏幕左托夹|1|M05|81.50×16.00×17.50|0.16/0.2|4道/30%|[下载](STL/05_front_face/P16_display_case_cradle_left_x01.stl)|
|P17|左右通用髋定子座|2|M01、M02|78.00×78.00×6.00|0.16/0.2|4道/30%|[下载](STL/00_shared_leg_parts/P17_hip_stator_mount_x02.stl)|
|P18|左右通用髋转子法兰|2|M01、M02|43.00×42.99×10.30|0.16/0.2|4道/30%|[下载](STL/00_shared_leg_parts/P18_hip_rotor_cnc_x02.stl)|
|P19|右膝定子套杯|1|M02|56.99×56.99×11.60|0.16/0.2|4道/30%|[下载](STL/02_right_leg/P19_knee_stator_cnc_x01.stl)|
|P20|左膝定子套杯|1|M01|56.99×56.99×11.60|0.16/0.2|4道/30%|[下载](STL/01_left_leg/P20_knee_stator_cnc_left_x01.stl)|
|P21|右OB内框|1|M02|56.99×173.99×7.50|0.16/0.2|4道/30%|[下载](STL/02_right_leg/P21_OB_inner_carrier_x01.stl)|
|P22|左OB内框|1|M01|56.99×173.99×7.50|0.16/0.2|4道/30%|[下载](STL/01_left_leg/P22_OB_inner_carrier_left_x01.stl)|
|P23|右OB外包主臂|1|M02|56.99×176.49×22.80|0.16/0.2|4道/30%|[下载](STL/02_right_leg/P23_OB_outer_shell_x01.stl)|
|P24|左OB外包主臂|1|M01|56.99×176.49×22.80|0.16/0.2|4道/30%|[下载](STL/01_left_leg/P24_OB_outer_shell_left_x01.stl)|
|P25|左右通用OA曲柄|2|M01、M02|44.00×79.99×22.80|0.16/0.2|4道/30%|[下载](STL/00_shared_leg_parts/P25_OA_one_piece_x02.stl)|
|P26|左右通用AC轴承连杆|2|M01、M02|31.00×160.99×8.00|0.16/0.2|4道/30%|[下载](STL/00_shared_leg_parts/P26_AC_bearing_link_x02.stl)|
|P27|右CW下臂|1|M02|44.00×184.99×15.00|0.16/0.2|4道/30%|[下载](STL/02_right_leg/P27_CW_one_piece_x01.stl)|
|P28|左CW下臂|1|M01|44.00×184.99×15.00|0.16/0.2|4道/30%|[下载](STL/01_left_leg/P28_CW_one_piece_left_x01.stl)|
|P29|通用轮辋|2|M01、M02|89.98×90.00×40.50|0.16/0.2|4道/30%|[下载](STL/00_shared_leg_parts/P29_wheel_rim_x02.stl)|
|LC01|轴承外圈压盖|6|M01、M02|28.00×27.99×0.80|0.1/0.1|4道/100%|[下载](STL/00_shared_leg_parts/LC01_bearing_keeper_D28_D16_8_t0_8_x06.stl)|
|LC02|双端内螺纹关节轴销|6|M01、M02|6.00×6.00×14.05|0.1/0.1|4道/100%|[下载](STL/00_shared_leg_parts/LC02_female_pin_D6_L14_05_x06.stl)|
|LC03|内侧一体带肩衬套|6|M01、M02|8.40×8.40×3.75|0.1/0.1|4道/100%|[下载](STL/00_shared_leg_parts/LC03_flanged_bush_inner_D8_D8p4_L3p75_x06.stl)|
|LC04|外侧一体带肩衬套|6|M01、M02|8.40×8.40×4.20|0.1/0.1|4道/100%|[下载](STL/00_shared_leg_parts/LC04_flanged_bush_outer_D8_D8p4_L4p20_x06.stl)|
|LC05|轴销薄防脱挡片|12|M01、M02|9.00×9.00×0.20|0.2/0.2|3道/100%|[下载](STL/00_shared_leg_parts/LC05_axis_washer_D9_d2_2_t0_2_x12.stl)|
|LC06|OA装配限位肩销|2|M01、M02|7.00×7.00×8.20|0.1/0.1|4道/100%|[下载](STL/00_shared_leg_parts/LC06_OA_angular_stop_M3_D4_x02.stl)|
|P30|配电通信一体安装架|1|M07|59.00×111.00×70.00|0.2/0.2|4道/20%|[下载](STL/07_service_carrier/P30_electrical_service_carrier_x01.stl)|
|P31|背部USB扩展坞压托|1|M06|12.50×104.50×13.00|0.16/0.2|4道/30%|[下载](STL/06_shell/P31_USB_hub_rear_clamp_x01.stl)|
|P32|后充电口可换安装板|1|M06|22.00×34.00×2.50|0.16/0.2|4道/30%|[下载](STL/06_shell/P32_DC_charge_replaceable_plate_x01.stl)|

## 薄件与支撑

- LC05总厚0.20 mm，按0.20 mm首层单独切片。不得加厚成普通垫圈；若无法完整取下，用同厚片材按原轮廓裁切。
- LC01～LC06为精细形状样件。模型中螺纹主要用底孔/外圆表达，打印后不能直接假定已有可用螺纹。
- 前壳/后壳按维修分缝落床，内腔、固定小手和悬空耳片使用可移除支撑。不要把支撑封在不可达的腔内。
- 小销和衬套建议多件分散同时打印，使用打印机既有最小层时间；不另给未经设备验证的速度或温度。
- [逐件后处理及精配限制](FIT_NOTES.md)优先于外观上的“装得上”；支撑残留、翘曲和缩孔可能造成假干涉。

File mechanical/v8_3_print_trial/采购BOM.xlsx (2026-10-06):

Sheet: 标准件采购
V8.3 打印试装标准件采购
定制结构件全部由打印包提供；这里只采购真实螺钉、螺母、垫圈、销和轴承。
 |  |  |  | 需求总件数 | 274 | 需购总件数 | 274 | 23 类
来源：V8.2 完整 BOM；本次按单台、断电机械试装整理。
黄色为可编辑数量，空白表示尚未核实。件数不等于采购包装数。
ID | 零件 | 采购规格 | 材料/等级 | 需求/件 | 在手/件 | 备件/件 | 需购买/件 | 使用模块 | 装配与采购注意
LH01 | 内六角圆柱头螺钉 | ISO4762 M3×8 | 钢8.8；发黑 | 46 | 0 | 0 | 46 | M01、M02、M04、M05、M07 | 同规格合并，含轮辋 12 枚；按实际安装位置分装。
LH02 | 内六角圆柱头螺钉 | ISO4762 M3×16 | 钢8.8；发黑 | 14 | 0 | 0 | 14 | M01、M02、M06 | OA 到转子需此长度；不可换 M3×8。
LH03 | 低头小头螺钉 | NBK SLH-M3-6-SD；头Ø4.5×2，内六角2 | SWCH45K；8.8；发黑 | 20 | 0 | 0 | 20 | M01、M02 | 必须小头 Ø4.5×2；普通 M3 圆柱头不适配。
LH04 | 低头小头螺钉 | NBK SLH-M3-8-SD；头Ø4.5×2，内六角2 | SWCH45K；8.8；发黑 | 8 | 0 | 0 | 8 | M01、M02 | 法兰侧锁紧；必须小头 Ø4.5×2。
LH05 | 超薄头内六角花形螺钉 | NBK SETS-M2-4；头Ø4×0.5，TX4 | SUSXM7；A2；原厂本色 | 30 | 0 | 0 | 30 | M01、M02 | 轴承压盖 18 枚、轴销防脱 12 枚；TX4 工具。
LH06 | 沉头内六角螺钉 | DIN7991 M3×10；头≤Ø6×1.7，90°，内六角2 | 钢010.9；发黑 | 8 | 0 | 0 | 8 | M01、M02 | 头 Ø6×1.7；不能直接换大头 ISO10642。
LH07 | 沉头内六角螺钉 | DIN7991 M3×6；头≤Ø6×1.7，90°，内六角2 | 钢010.9；发黑 | 12 | 0 | 0 | 12 | M01、M02 | 头 Ø6×1.7；用于髋电机定子。
LH08 | 沉头内六角螺钉 | DIN7991 M4×12；头≤Ø8×2.3，90°，内六角2.5 | 钢010.9；发黑 | 8 | 0 | 0 | 8 | M01、M02 | 头 Ø8×2.3；每腿 4 枚，勿重复计机身。
LH09 | 普通平垫圈 | ISO7089 M4；Ø4.3/Ø9×0.8 | 钢200HV；镀锌 | 8 | 0 | 0 | 8 | M03 | 每个 M4 接口一片，维持原厚度。
LH10 | 六角螺母 | ISO4032 M4；AF7×3.2 | 钢8级；镀锌 | 8 | 0 | 0 | 8 | M03 | 配 M4 沉头螺钉，不换高型防松螺母。
LH11 | 定位圆柱销 | DIN6325 Ø4m6×10（Norelem03320-04X10） | 工具钢；淬硬磨削60±2HRC；本色 | 6 | 0 | 0 | 6 | M01、M02 | 每髋 3 枚；打印孔清孔后轻装，禁止强压。
LH12 | 深沟球轴承 | NSK626ZZ1；6×19×6；金属防尘盖 | 原厂轴承钢 | 6 | 0 | 0 | 6 | M01、M02 | A/B/C 各 1 个/腿；不要换 C3/MC3 游隙。
BH01 | 沉头内六角螺钉 | DIN7991 M3x0.5 x 8 | 钢010.9；发黑 | 16 | 0 | 0 | 16 | M03 | 头 Ø6×1.7，90°；不要直接换大头 ISO10642。
BH03 | 内六角圆柱头螺钉 | ISO4762 M3x0.5 x 10 | 钢8.8；发黑 | 10 | 0 | 0 | 10 | M04、M05、M06 | 含后充电安装板紧固件。
BH04 | 内六角圆柱头螺钉 | ISO4762 M3x0.5 x 12 | 钢8.8；发黑 | 16 | 0 | 0 | 16 | M05、M06、M07 | 含电气安装架到托盘的紧固件。
BH05 | 内六角圆柱头螺钉 | ISO4762 M3x0.5 x 20 | 钢8.8；发黑 | 8 | 0 | 0 | 8 | M05、M06 | 显示器托夹及机壳连接。
BH06 | 内六角圆柱头螺钉 | ISO4762 M2.5x0.45 x 16 | 钢8.8；发黑 | 2 | 0 | 0 | 2 | M04 | 光头外径 ≤4.5、高 ≤2.5，内六角 2。
BH07 | 六角螺母 | ISO4032 M3x0.5; AF5.5 x t2.4 | 钢8；镀锌 | 26 | 0 | 0 | 26 | M04、M05、M06、M07 | AF5.5、厚 ≤2.4；不换高型尼龙防松螺母。
BH08 | 六角螺母 | ISO4032 M2.5x0.45; AF5 x t2 | 钢8；镀锌 | 6 | 0 | 0 | 6 | M04、M07 | AF5、厚 ≤2；不换高型尼龙防松螺母。
BH09 | 普通平垫圈 | ISO7089 M3; ID3.2 x OD7 x t0.5 | 钢200 HV；镀锌 | 4 | 0 | 0 | 4 | M04 | 4 片为规定分压垫圈，不用于补长度。
EH01 | 内六角圆柱头螺钉 | ISO4762 M1.6×10 | 钢8.8；发黑 | 4 | 0 | 0 | 4 | M07 | 裸板 USB2CAN 用 4 枚，先核对工具空间。
EH02 | 六角螺母 | ISO4032 M1.6；AF3.2×1.3 | 钢8；镀锌 | 4 | 0 | 0 | 4 | M07 | 裸板 USB2CAN 用；AF3.2、厚1.3。
EH03 | 内六角圆柱头螺钉 | ISO4762 M2.5×12 | 钢8.8；发黑 | 4 | 0 | 0 | 4 | M07 | 配电板用；光头外径 ≤4.5。

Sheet: 其他物料核实
其他物料与待选型项
轮胎和耗材库存尚未确认；未确定规格的项目先核实，不按确定商品下单。
来源：V8.2 完整 BOM；本次按单台、断电机械试装整理。
黄色为可编辑数量，空白表示尚未核实。件数不等于采购包装数。
ID | 物料 | 规格或已知尺寸 | 本阶段安排 | 需求 | 在手 | 备件 | 待补数量 | 核实状态 | 装配与采购注意
E08 | 弹性轮胎 | 外径100/内径86/宽32 mm | 按实物试装核实 | 2 |  | 0 | 待核实 | 库存待核实 | 仅装配试放可暂缺；要装轮胎时核实在手型号与轮辋匹配。
C01 | 屏幕后软垫 | 4×8×0.5 mm，4块 | 按实物试装核实 | 4 |  | 0 | 待核实 | 库存待核实 | 接触显示器金属边框，压缩后厚0.5；不可压玻璃。
C02 | 电池束带 | 10×300 mm；底部单层厚≤1.0 mm | 按实物试装核实 | 2 |  | 0 | 待核实 | 库存待核实 | 用于固定已有电池；厚≤1，搭接与扣头避开 DC 口。
T01 | 电源保护与主回路分断器件 | 依电气额定值选型，不能由AC开关标称替代 | 走线或后续通电 | 待定 |  | 0 | 待定 | 数量及规格待定 | 本阶段断电试装可延后；额定电流与 DC 分断方案未确定。
T02 | 后部充电DC母座 | 插合DC5.5×2.1；面板安装孔/螺纹/载流待确定 | 走线或后续通电 | 1 |  | 0 | 待核实 | 规格仍待选型 | 本阶段可延后；安装板仅导孔，先选母座再定最终孔。
T03 | 线束、插头与绝缘护线件 | 待电气方案与实物确认 | 走线或后续通电 | 待定 |  | 0 | 待定 | 数量及规格待定 | 本阶段可延后；数量/针脚/长度待实际配线，不按 0 处理。
T04 | 螺纹防松与标记耗材 | 待电气方案与实物确认 | 走线或后续通电 | 待定 |  | 0 | 待定 | 数量及规格待定 | 本阶段可延后；打印件不套用金属拧紧扭矩或未验证胶水。
C03 | 扩展坞防响软垫 | 2×15×0.5 mm；两片，0.5为装配间隙目标 | 按实物试装核实 | 2 |  | 0 | 待核实 | 库存待核实 | 压缩后装配间隙0.5；仅压非接口壳边。
C04 | USB3数据延长线 | USB-A公→USB-A母；250 mm | 走线或后续通电 | 1 |  | 0 | 待核实 | 库存待核实 | 可留至走线试装；支持 USB3 数据，实际插头尺寸待核对。
T05 | 机壳及托盘护线套 | 适用Ø10面板孔、3mm板厚；净孔≥7mm | 走线或后续通电 | 3 |  | 0 | 待核实 | 规格仍待选型 | 本阶段可延后；护线套型号及开合方式仍需按插头确定。
可选替代，仅打印失败后启用
对应ID | 精细定制件 | 必须保持的尺寸 | 替代条件 | 替代用量 | 单位 | 默认购买 | 原打印件 | 采购方式
LC01 | 轴承外圈压盖 | Ø28/Ø16.8×0.8；3-Ø2.2 PCD24 | 按打印试装结果 | 6 | 件 | 0 | 保留在打印清单 | 按原图定制 | 打印翘曲时用同厚片料按原孔阵列制作；与打印件二选一。
LC02 | 关节轴销 | Ø6×14.05；双端M2×0.4 | 按打印试装结果 | 6 | 件 | 0 | 保留在打印清单 | 按原图定制 | STL仅有底孔，打印后需手攻牙。无牙光杆只能检查同轴，不能等效防脱；按需同尺寸加工。
LC03 | 内侧带肩衬套 | Ø8/Ø6.05×2.5＋肩Ø8.4/Ø6.2×1.25 | 按打印试装结果 | 6 | 件 | 0 | 保留在打印清单 | 按原图定制 | 微小凸肩/间隙不适合用FDM判断精配；需要精配验收时才用同尺寸铜套。
LC04 | 外侧带肩衬套 | 肩Ø8.4/Ø6.2×1.70＋Ø8/Ø6.05×2.5 | 按打印试装结果 | 6 | 件 | 0 | 保留在打印清单 | 按原图定制 | 微小凸肩/间隙不适合用FDM判断精配；需要精配验收时才用同尺寸铜套。
LC05 | 轴销防脱挡片同尺寸薄片替代 | 外径9 / 孔2.2 / 厚0.20 mm | 按打印试装结果 | 12 | 件 | 0 | 保留在打印清单 | 按原图定制 | 原 LC05 仍在打印清单；0.2 mm 仅单层，易翘曲或破损。断电试装可改用同尺寸0.20 mm PET片或钢片，替换12片，不叠加；不得用更厚标准垫圈。
LC06 | OA限位肩销 | M3×3；Ø4肩长4.2；Ø7×1头 | 按打印试装结果 | 2 | 件 | 0 | 保留在打印清单 | 按原图定制 | STL名义外圆不含真实牙；可观察限位位置。普通M3螺钉不能等效；按需同尺寸加工。

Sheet: 已有设备核对
已有电机与电子模块核对
用户已确认已有这些设备，使用实物装配；本表仅核对数量与版本，不重复采购。
来源：V8.2 完整 BOM；本次按单台、断电机械试装整理。
黄色仅记录核对结果；本次采购始终为 0，缺件需另行确认。
ID | 设备 | 型号与安装包络 | 在手状态 | 整机需求 | 单位 | 本次采购 | 核对结果 | 模块 | 装配与采购注意
E01 | J4310关节电机 | DM-J4310-2EC，24V，V1.1驱动 | 用户已确认已有 | 4 | 件 | 0 | 待实物核对 | M01、M02 | 使用在手实物试装；随设备自带零件不重复采购。
E02 | 轮毂电机 | DM-H6215 | 用户已确认已有 | 2 | 件 | 0 | 待实物核对 | M01、M02 | 使用在手实物试装；随设备自带零件不重复采购。
E03 | 开发套件 | Jetson Orin Nano官方开发套件 | 用户已确认已有 | 1 | 件 | 0 | 待实物核对 | M04 | 使用在手实物试装；随设备自带零件不重复采购。
E04 | 深度相机 | RealSense D435 | 用户已确认已有 | 1 | 件 | 0 | 待实物核对 | M05 | 使用在手实物试装；随设备自带零件不重复采购。
E05 | 惯性测量单元 | 超核HI13R2 USB版 | 用户已确认已有 | 1 | 件 | 0 | 待实物核对 | M04 | 使用在手实物试装；随设备自带零件不重复采购。
E06 | 5寸显示器 | GK-HD V3，122×78×14.5 mm | 用户已确认已有 | 1 | 件 | 0 | 待实物核对 | M05 | 使用在手实物试装；随设备自带零件不重复采购。
E07 | E626S电池包及磁吸底座 | 用户确认24V等级E626S；本体85.6×61.6×42 mm，含磁底44.5 mm | 用户已确认已有 | 1 | 件 | 0 | 待实物核对 | M04 | 使用在手实物试装；随设备自带零件不重复采购。
E09 | 顶部自锁电源开关及插接座 | M16×1，法兰Ø17.8，AF19螺母；带插接座深47.5 mm | 用户已确认已有 | 1 | 件 | 0 | 待实物核对 | M06 | 使用在手实物试装；随设备自带零件不重复采购。
E10 | 背部四口USB扩展坞 | 104×30×10 mm；一体USB-A上行线150 mm，线径约4.8 mm | 用户已确认已有 | 1 | 件 | 0 | 待实物核对 | M08 | 使用在手实物试装；随设备自带零件不重复采购。
E11 | 达妙双路USB2CANFD裸板 | DM-USB2CANFD Dual；使用提供模型中的裸板 | 用户已确认已有 | 1 | 件 | 0 | 待实物核对 | M07 | 使用在手实物试装；随设备自带零件不重复采购。
E12 | 用户配电转接板 | 3D_PCB1_2026-09-28.step 对应板组件 | 用户已确认已有 | 1 | 件 | 0 | 待实物核对 | M07 | 使用在手实物试装；随设备自带零件不重复采购。
E13 | 24→19 V电源转换模块 | 主体45×25×20 mm；总长58 mm；孔距51 mm，孔Ø4 mm | 用户已确认已有 | 1 | 件 | 0 | 待实物核对 | M07 | 使用在手实物试装；随设备自带零件不重复采购。

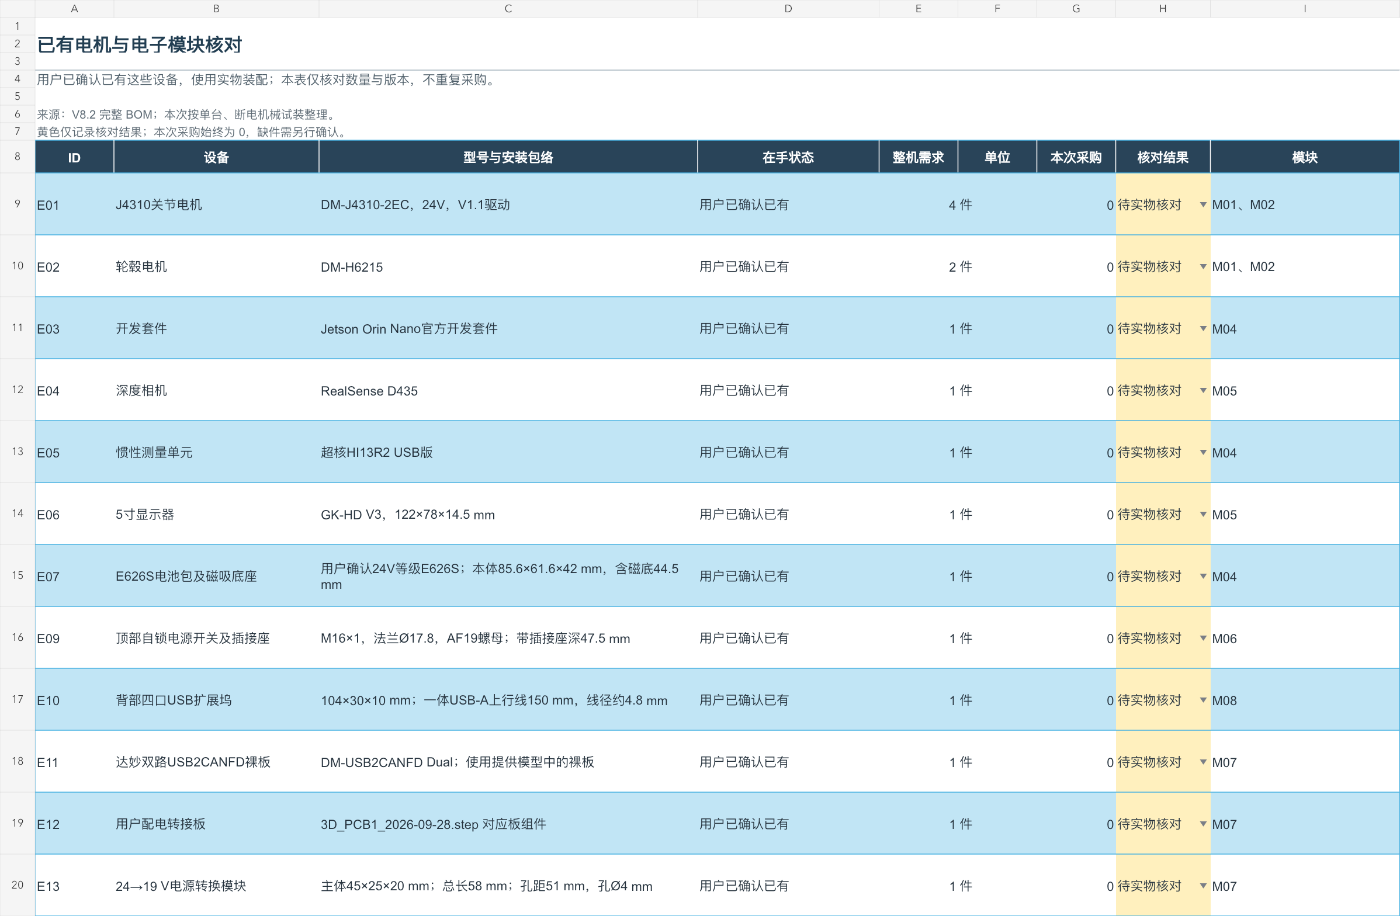
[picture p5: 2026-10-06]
mechanical/v8_3_print_trial/verification/bom/owned.png

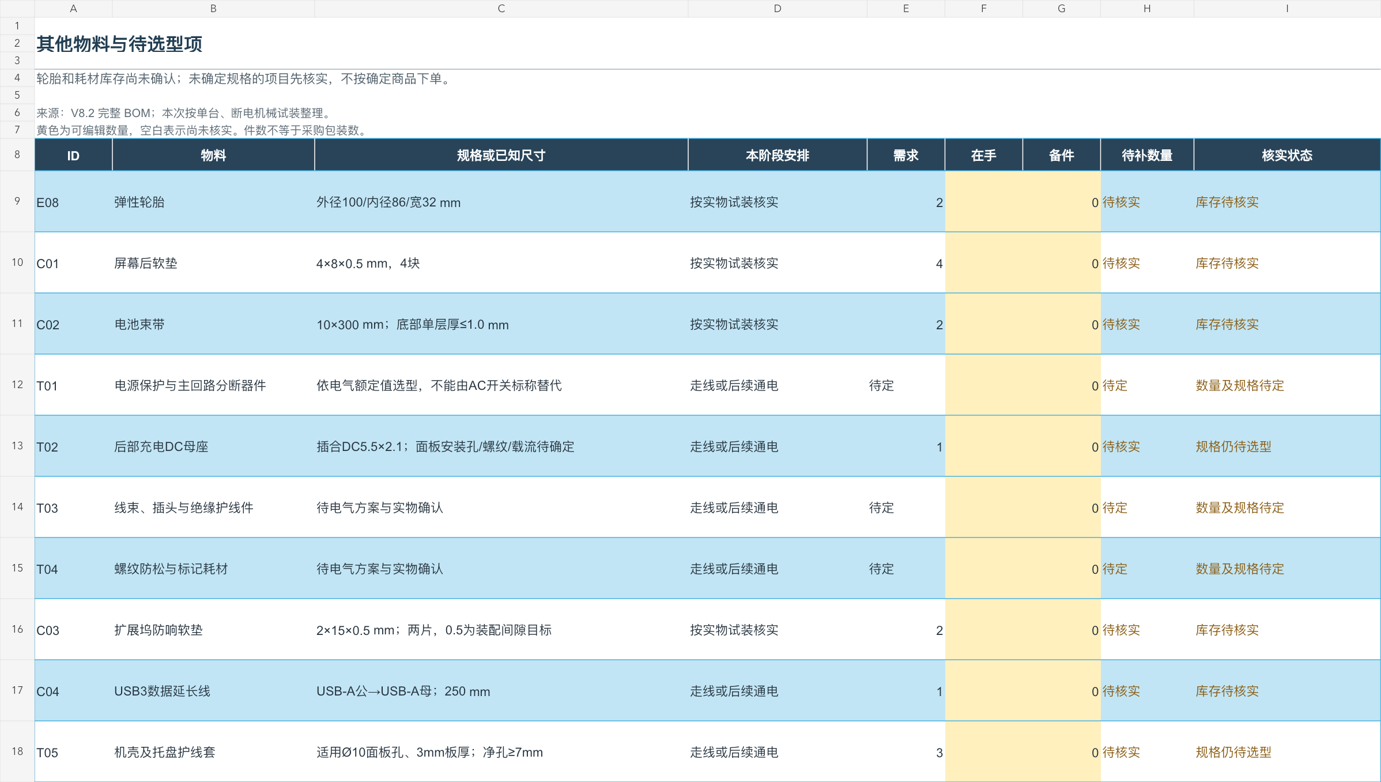
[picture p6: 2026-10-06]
mechanical/v8_3_print_trial/verification/bom/pending.png

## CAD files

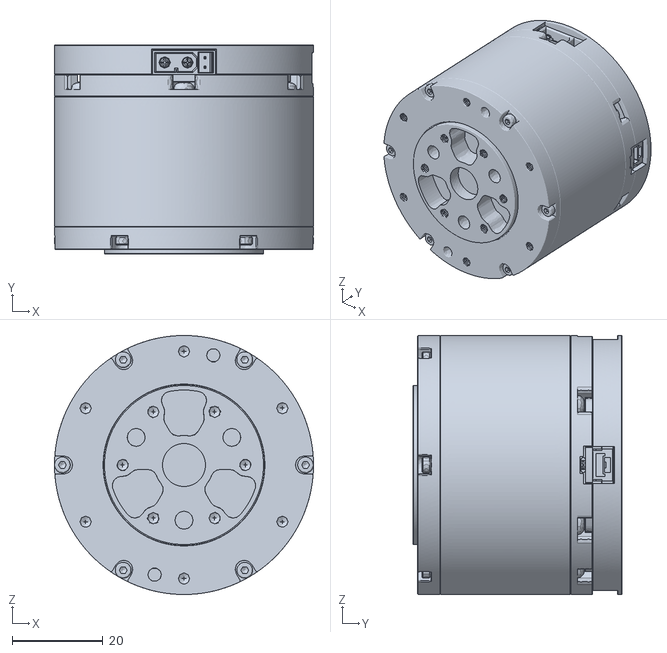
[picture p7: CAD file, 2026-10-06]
assets/meshes/DM-J4310-2EC-V1.1.stl
57.0 x 46.0 x 57.0

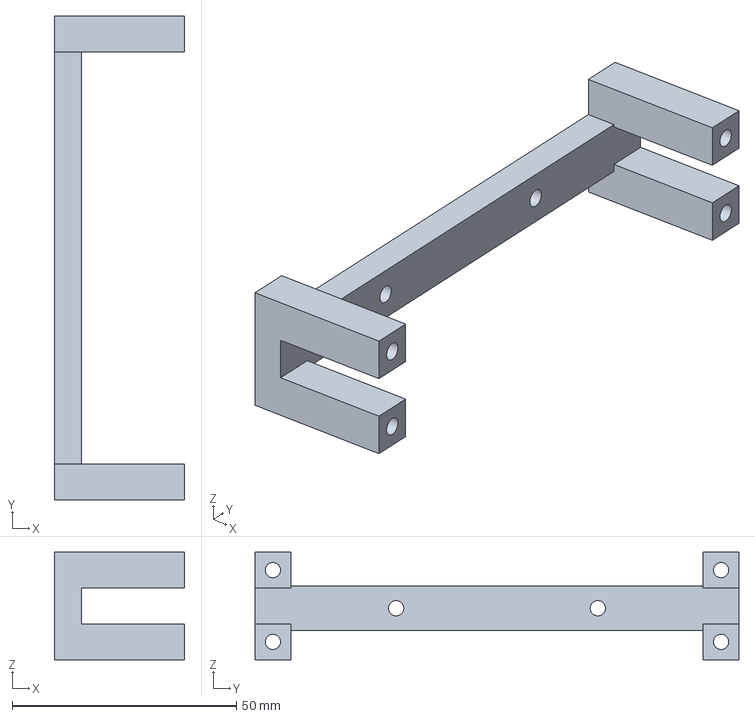
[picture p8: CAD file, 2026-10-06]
mechanical/v8_3/alternates/D435_embedded_bracket_depth26p05.step
29.0 x 108.0 x 24.0 mm

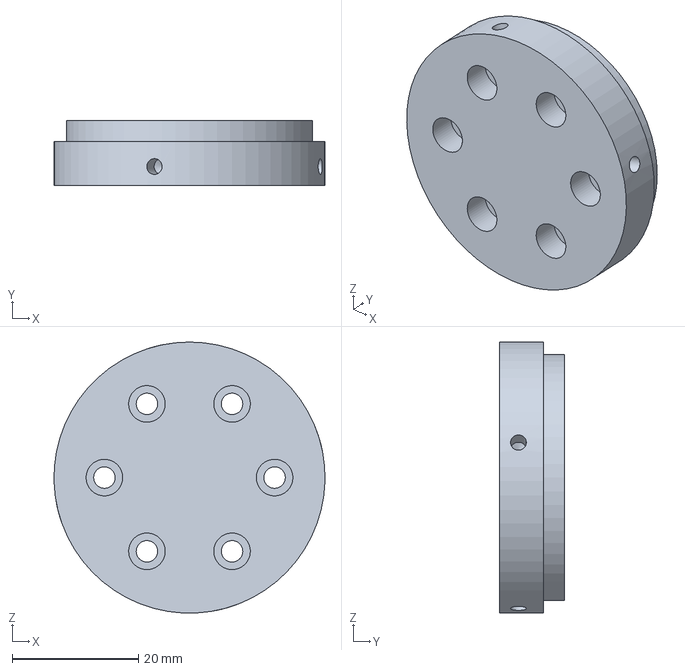
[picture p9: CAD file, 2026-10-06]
mechanical/v8_3/cnc/hip_rotor_cnc_left.step
43.0 x 10.3 x 43.0 mm

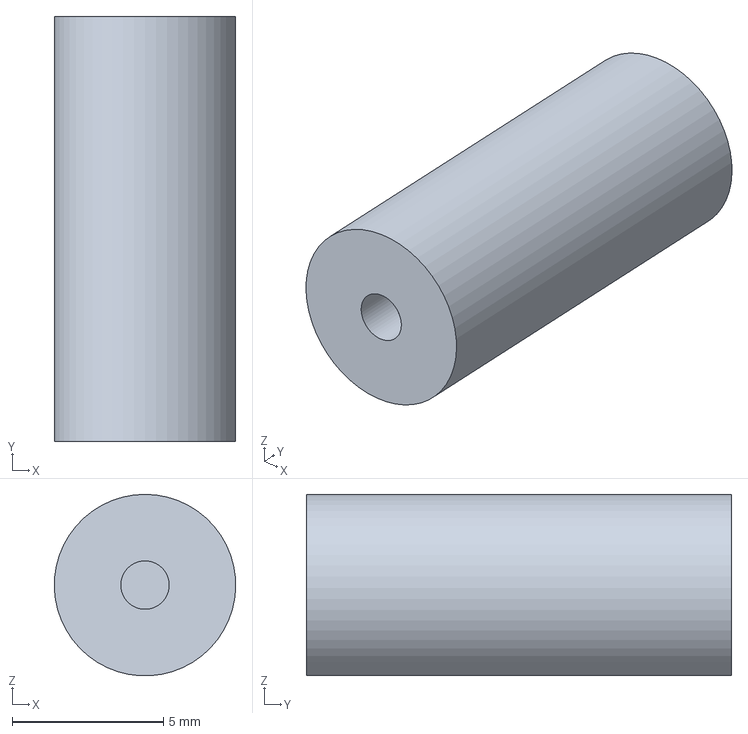
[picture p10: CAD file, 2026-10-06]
mechanical/v8_3/manufacturing/metal/LC02_female_pin_D6_L14_05.step
6.00 x 14.1 x 5.99 mm

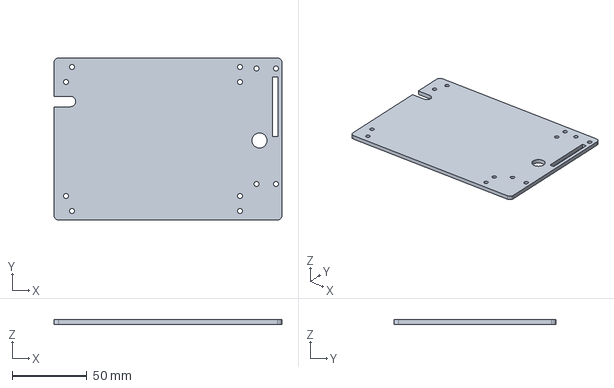
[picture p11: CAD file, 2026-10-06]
mechanical/v8_3/manufacturing/print/P10_electronics_tray.step
152.0 x 108.0 x 3.00 mm

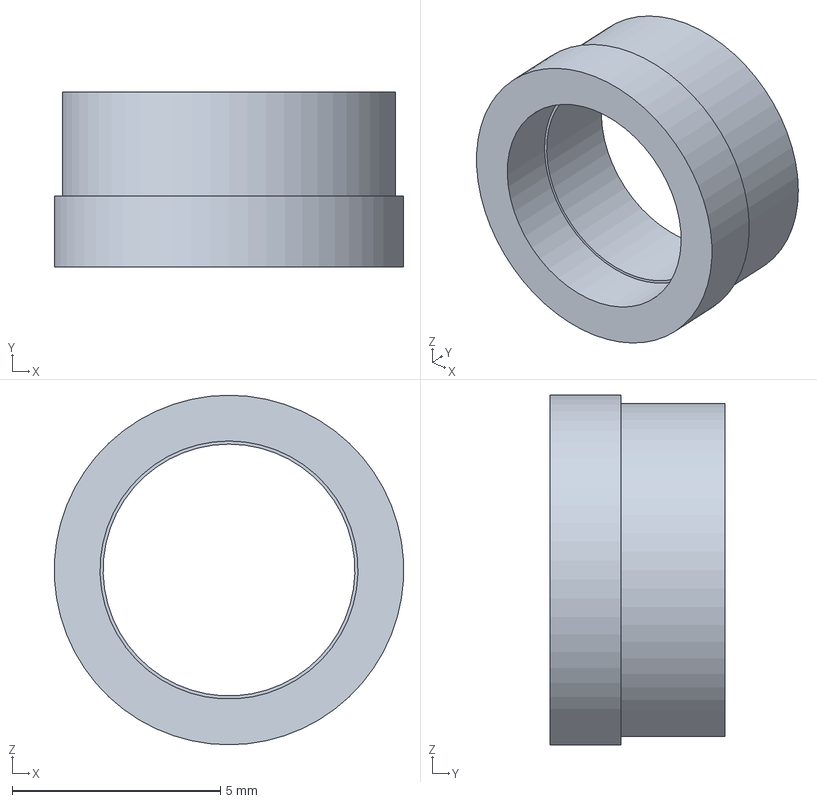
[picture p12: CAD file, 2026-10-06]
mechanical/v8_3/metal_hardware/flanged_bush_outer_D8_D8p4_L4p20.step
8.39 x 4.20 x 8.40 mm

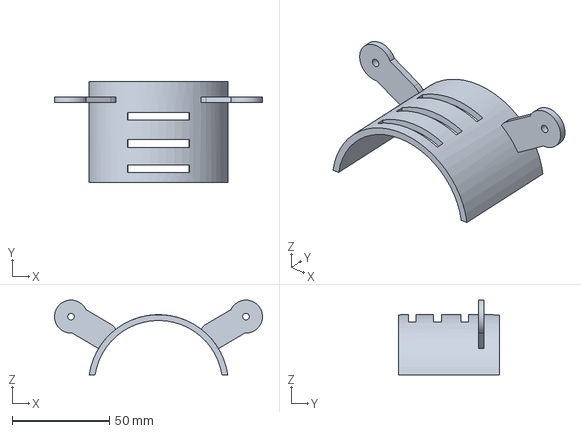
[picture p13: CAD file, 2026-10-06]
mechanical/v8_3/step/shoulder_fairing_left.step
107.0 x 51.8 x 38.5 mm

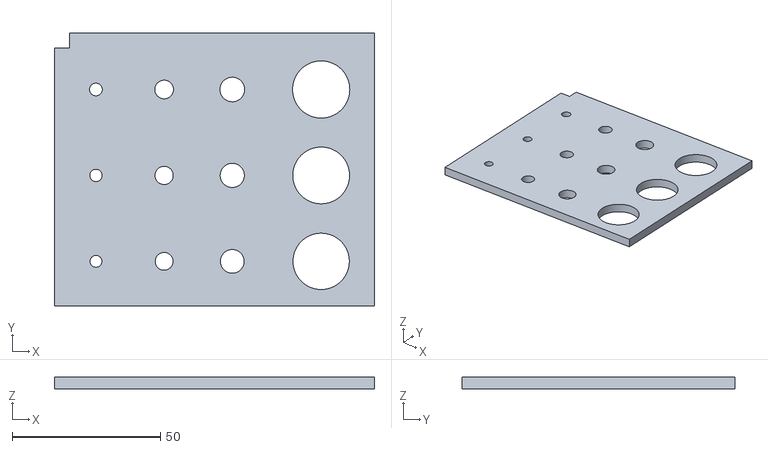
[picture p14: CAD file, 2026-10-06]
mechanical/v8_3_print_trial/00_optional_calibration/CALI_hole_coupon_108x92_x01.stl
108.0 x 92.0 x 4.00

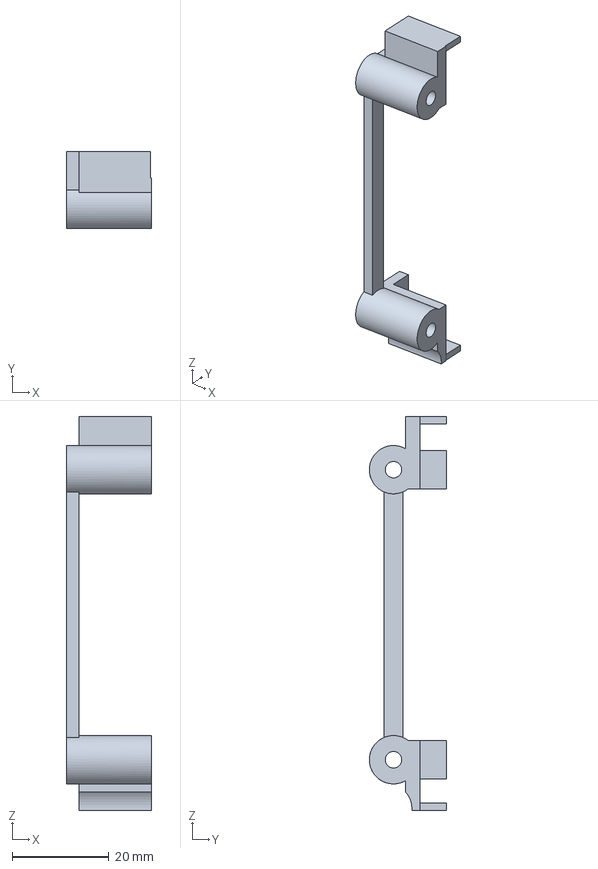
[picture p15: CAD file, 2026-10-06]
mechanical/v8_3_print_trial/STEP_reference/P16_display_case_cradle_left.step
17.5 x 16.0 x 81.5 mm

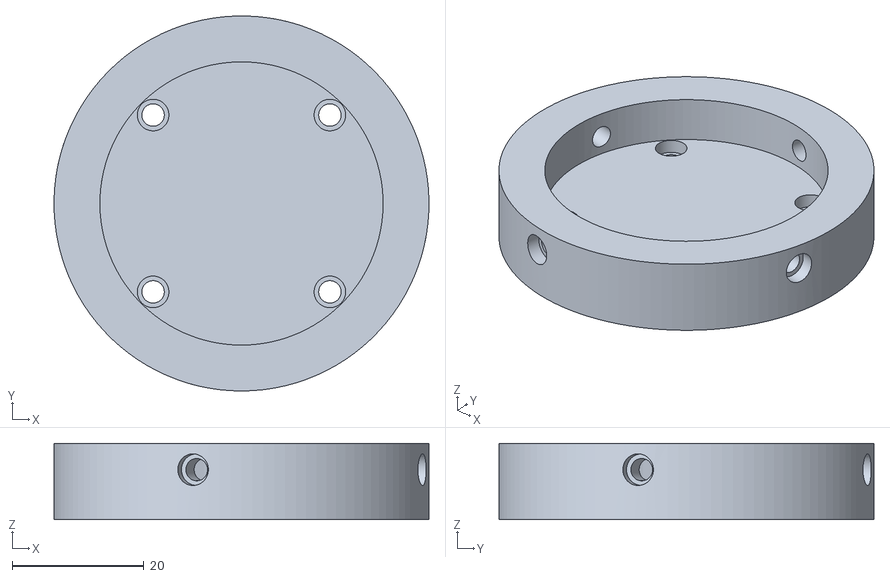
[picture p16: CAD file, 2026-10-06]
mechanical/v8_3_print_trial/STL/01_left_leg/P20_knee_stator_cnc_left_x01.stl
57.0 x 57.0 x 11.6

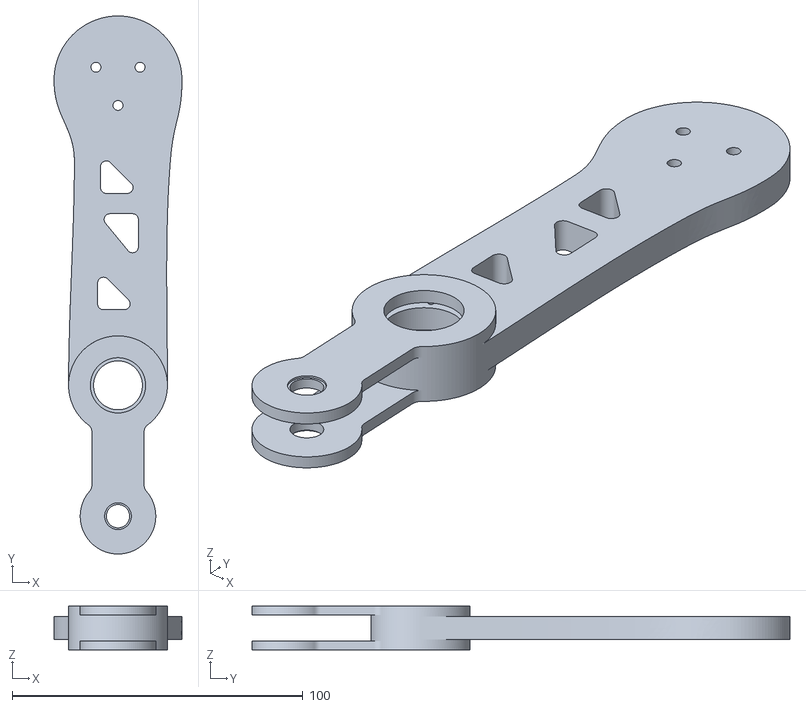
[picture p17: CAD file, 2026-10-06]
mechanical/v8_3_print_trial/STL/02_right_leg/P27_CW_one_piece_x01.stl
44.0 x 185.0 x 15.0

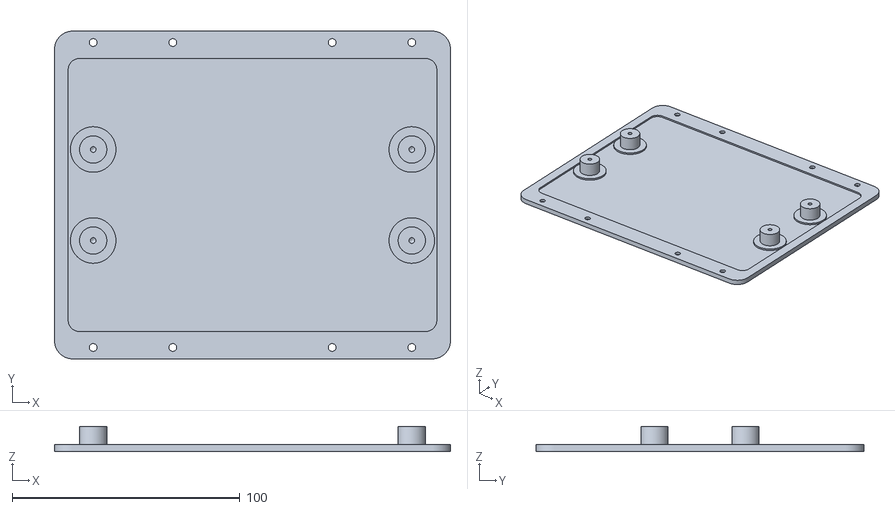
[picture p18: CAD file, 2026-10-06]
mechanical/v8_3_print_trial/STL/03_chassis/P01_chassis_belly_plate_x01.stl
174.0 x 144.0 x 11.0

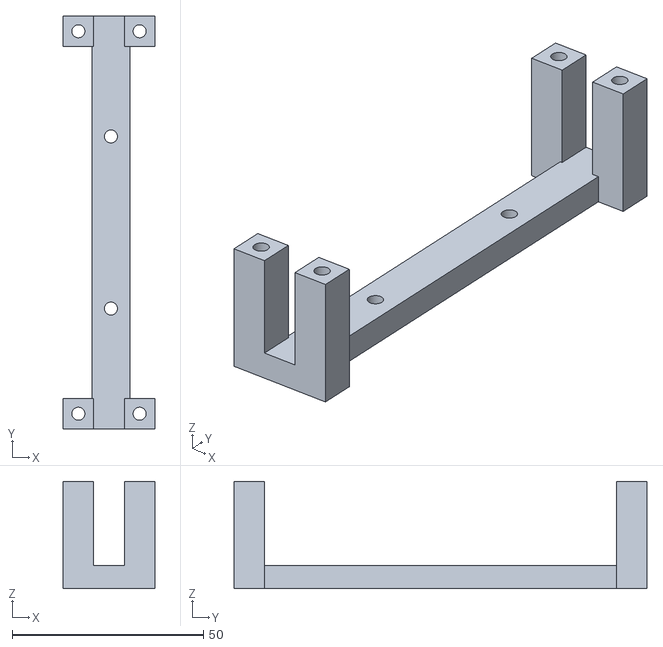
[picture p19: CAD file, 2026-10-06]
mechanical/v8_3_print_trial/STL/05_front_face/P13_D435_embedded_bracket_x01.stl
24.0 x 108.0 x 28.0

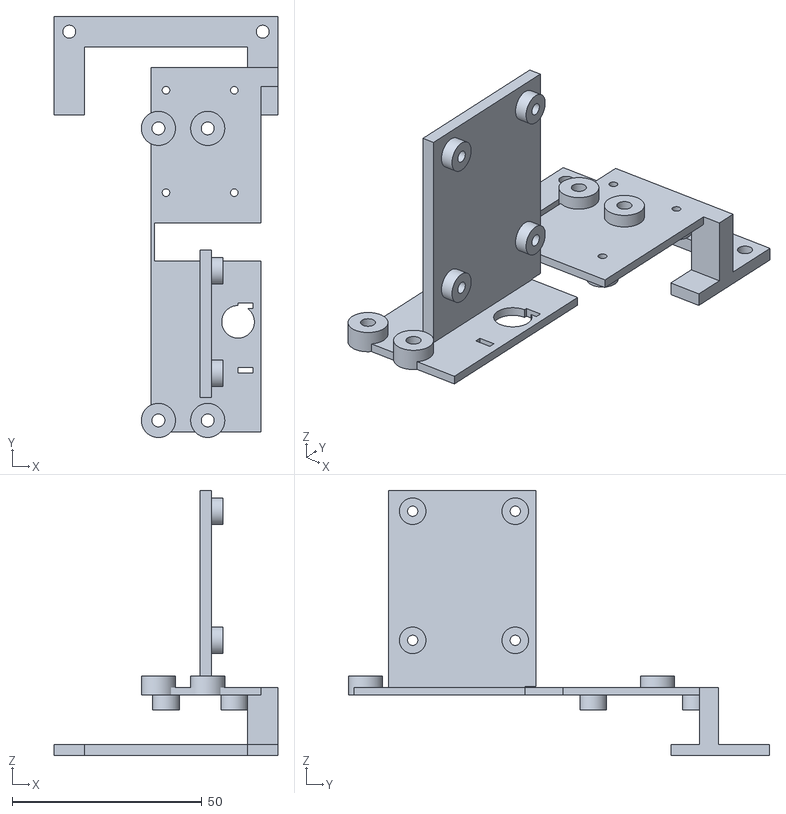
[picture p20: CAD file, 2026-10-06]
mechanical/v8_3_print_trial/STL/07_service_carrier/P30_electrical_service_carrier_x01.stl
59.0 x 111.0 x 70.0

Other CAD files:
mechanical/v8_3/wheel_leg_v8_3.FCStd
mechanical/v8_3_print_trial/STL/04_electronics_bay/P10_electronics_tray_x01.stl
mechanical/v8_3_print_trial/STL/06_shell/P08_shoulder_fairing_right_x02.stl
references/dm-tools/USB2CANFD_Dual/模型/usb2canfd_v2_1-double.stp
assets/meshes/DM-H6215.stl
mechanical/v1/cnc/hip_rotor_cnc.step
mechanical/v1/cnc/knee_stator_cnc.step
mechanical/v1/print/active_arm_OA.stl
mechanical/v1/print/battery_tray.stl
mechanical/v1/print/bearing_fit_coupon.stl
mechanical/v1/print/chassis_lid.stl
mechanical/v1/print/chassis_lower_shell.stl
mechanical/v1/print/coupler_AC.stl
mechanical/v1/print/electronics_tray.stl
mechanical/v1/print/fixed_arm_OB.stl
mechanical/v1/print/hip_stator_mount.stl
mechanical/v1/print/output_BCW.stl
mechanical/v1/print/wheel_rim.stl
mechanical/v1/step/active_arm_OA.step
mechanical/v1/step/battery_tray.step
mechanical/v1/step/bearing_fit_coupon.step
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

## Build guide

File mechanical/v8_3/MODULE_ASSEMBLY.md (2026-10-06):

# V8.2 模块预装与总装

先装两腿与空机架，再装电池，随后放入机外预装的电子盘/配电通信模块，最后接入前脸与后盖模块。外壳不承担腿部主载荷。+X朝前，+Z向上；从背部看右侧为−Y。

本版保留V8.1腿部几何和紧固关系。腿部内部工艺仍见[基线腿部装配](baseline_v81/LEG_ASSEMBLY.md)和[基线公差](baseline_v81/LEG_FITS.md)。下文更新电器模块及外壳安装，不能用旧版“完整电子盘先抬4 mm再后抽”的检查直接证明本版新增竖板也能走同一路径。

## 模块分工

|CAD分组|预装内容|安装依赖|
|---|---|---|
|M01/M02|左右整腿、电机、轴承销套及轮组|先接空M03，四颗髋座M4预先放入|
|M03|金属底板、左右髋框、前后横框|保留电器仓空置供腿部螺母和工具操作|
|M04|电池/窄托、Jetson/PETG电子盘、IMU桥|电池先装；电子盘与M07可在机外组合|
|M05|5寸屏、D435及前脸|线缆预接好，再封前脸|
|M06|前主壳、后盖、肩罩、开关、后接口夹持件|开关随前壳预装；后盖同M08机外组合|
|M07|裸USB2CAN、用户分配PCB、24→19 V模块及一体PETG支架|先机外装板和模块，再以4颗M3×12安装到电子盘|
|M08|四口USB扩展坞及连接线|随后盖装入；夹具/盖的CAD对象仍归M06，不重复计数|

`modules/M01.step`至`M08.step`保留共同坐标，便于组合检查；这些分组是装配层级，并不等于每组都能独立无条件抽出。

## 机外预装

1. **左右腿。** 沿用髋座和髋电机→两件髋膝法兰及膝电机→OB内座→从同轴开口装OA→AC/CW轴承与销套→OB外罩→限位销→轮组的顺序。髋座仍裸露时预放每侧4颗DIN7991 M4×12，临时防掉。不能把Ø3.2工具可通过当作Ø8螺钉头也能后装通过。
2. **电池模块。** E626S含磁底按85.6X×44.5Y×61.6Z放入窄托，DC侧朝上；离机穿好两条束带。底部仅一层、厚≤1 mm，搭接移到顶上并避开实际插头。电池400 g仍是含附件质量预算。详见[基线电池安装](baseline_v81/BATTERY.md)。
3. **M07服务支架。** 支架是一件PETG结构，USB2CAN平放、Type-C朝−Y；用户PCB竖装，PCB面约X66，范围Y5..37、Z−13..26 mm，DC口朝+Z。转换器放在−Y侧支臂上。裸CAN用4颗M1.6×10和配套螺母；PCB用4颗M2.5×12及配套螺母，直接使用核对过包络的螺钉头，不任意加入大直径垫片挤压板上元件；转换器用2颗M3×8及螺母。型号/长度以最终BOM为准。
4. **电子盘组合。** 在台面上托住电子盘，让M07竖背板X60..63穿过盘上3.6 mm槽。4颗M3×12从上方穿入，螺母由盘下安装，中心为X49/62、Y−30/+47 mm。先完成这些盘下螺母，再装入机身。Jetson继续使用原底座和原托夹；各面向+X的USB、Type-C、DP与电源线先插好、留应力释放，避免封前脸后再盲插。盘后缘X−75/Y25有7 mm宽U形开口槽，扩展坞不可拆线从开口侧放入，不要求模塑USB插头穿过圆孔。服务架X70/Y21的Ø8.6孔用于穿线；其中央腿束通道加宽为10 mm，范围X48..77/Y−5..5/Z36..38，不改变4个安装点。实际插头和整束净空需分别核对。
5. **顶部开关。** 前壳顶孔Ø16.3，壁厚3 mm；开关轴心X60/Y0，外法兰在顶面，AF19螺母由壳内旋紧，再接插座。图示插座组合总深47.5 mm，不能只按35 mm裸开关判断空间。开关DC触点与LED电压尚未确认，装上不代表可以通电测试整机负载。
6. **后盖与扩展坞。** 四口朝−X，从后盖内部放入104×30×10 mm坞体；左右保持边和底托定位，再装一件压托，以2颗M3×16及螺母固定。耳座X−56/Y±47，后盖预装结构最大横宽109 mm，可与原后框116 mm开口比较；仍需对实际插头和线束试装。两片2×15×0.5 mm软垫放在坞顶X−63..−61、Y中心±35、Z10..10.5，压非端口壳边，不靠插座固定。
7. **充电接口板。** 位于背视右下，中心Y−46/Z−25 mm；可换片以2颗M3×10及螺母固定。片中Ø3仅定位导孔，不能直接安装DC母座。按最终母座开孔图扩孔或重打；插合5.5×2.1 mm不能当作面板孔径。
8. **前脸。** 屏幕/D435沿用V8.1安装；屏幕USB和HDMI均先接好，相机用USB3数据线。DP→HDMI转换必须包含在视频连接内，Jetson USB-C不能直接输出画面。

## 整机总装顺序

1. 预装空金属机架，电器模块及机壳暂不放入。两腿以180 mm髋轮距、Beta=0°轴向靠入，髋座四颗预放M4穿过机架孔，从机内放入M4垫片与螺母。
2. 四颗髋座螺钉不能在同一姿态全用直工具锁紧。后上X−30/Z+30在110 mm腿长处理；其余三颗在165 mm处理，Beta均为0°。移开工具后才调整姿态。外侧AF2.5直内六角杆Ø≤3.2，内侧AF7薄壁套筒外径≤10.5；详见[基线工具与两腿装配记录](baseline_v81/MODULE_ASSEMBLY.md)。
3. 恢复180 mm腿长。先放入完整电池/托盘模块，4颗M3×8从顶部固定。此时上方电子盘、IMU、前脸均未占据安装路径。
4. 将机外预装的Jetson电子盘+M07组合从上方对准安装；竖PCB随盘进入前下方空隙。不得以板上连接器顶靠电池托或前框。电子盘原4颗M3×8紧固点X−74/+38、Y±48保持不变。实际组合落装路径须在无电状态试装，不能把V8.1只带Jetson的连续扫掠结果移用到新增竖板。
5. 安装IMU桥及HI13R2，保持名义原点(0,0,85) mm和原轴向；线缆留柔性弯曲，不把线束绷紧到传感器。
6. 先将电池、分线及主开关相关线束接到可操作位置，再装前主壳。电池至顶部经过托盘Ø10过线孔；两侧腿束从机壳X89/Z54的Ø10孔引出。三处均按3 mm板厚选护线套，实际净孔要求至少7 mm，并核对带插头线束能否穿入。
7. 前脸用支架/台面承托，连接相机USB、屏幕USB与HDMI，检查前部短插头区域后锁前脸。各主机端口已按正/负Y上下层分配，详见[ELECTRICAL_INTEGRATION.md](ELECTRICAL_INTEGRATION.md)。
8. 扩展坞原150 mm线经电子盘后缘7 mm宽U形槽侧向放入，再用250 mm USB3 A公母延长线接Jetson正Y座上口，沿正Y侧高位路径绕行；接合点和多余线长绑在可拆卸服务位置。槽边清除打印毛刺，不将线缆压在盖板接缝中，也不强推模塑插头穿孔。后盖充电支路接在主开关前。接完后盖相关插头，再将完整后盖就位锁4颗M3×12；不得靠线缆悬挂盖板。
9. 理顺两腿弯折线环与固定端，最后装肩罩。先断电手动走完全腿行程，观察轮胎、OB/OA包夹槽和限位附近是否夹线。电气首次上电前核对极性、配电板线序、两路CAN终端及转换器输出。

## 走线图的边界

FreeCAD的“走线路径预留”组和`wiring_route_reference.step`是空间走廊，材料标签为`routing_allowance`；它们不进入实物装配STEP/STL、采购数或零件质量。球/圆柱折线不是线缆实际弯曲形状，路径端点是连接区域，不是确认过的插头接触端面。

`routing_allowances.json`列中心线长度、占位半径和端点；[路由检查](routing_validation.json)中的`all_clear`仅针对所列预留几何。[最终结构检查](electrical_final_validation.json)与[内部标注图](previews/internal_structure_annotated.png)供装配核对。最终选线还需考虑插头外壳、插拔行程、最小弯曲半径、服务余量及动态寿命；不能把折线长度直接当下料长度。线路分组表示动力、USB、视频和CAN功能关系，PCB内部网络和引脚不能由STEP推断。

## 拆卸维修

- 后盖：断开电池，拆后盖螺钉并用台面承托，拔扩展坞延长线接头与充电支路，再取下盖板。盖内可独立换扩展坞、压托、软垫和DC接口小板。
- 配电/通信：先断电、拆前脸/必要机壳，释放USB/电源/左右腿接头。服务架与电子盘之间的螺母在盘下；本版按机外组合维修设计，不承诺所有螺母可封壳盲拆。需要时连电子盘一起取出，在台面拆M07。
- 电池：先移开IMU桥和挡住向上通道的电子盘/M07、前脸及壳体，断开电池线，再拆4颗托盘M3×8，电池与托盘完整向上取出。无需拆腿，但不能从封闭后壳直接抽电池。
- Jetson：新增M07竖板改变电子盘包络，旧版“上抬4 mm后抽180 mm”的路径仅为历史证据。优先释放线缆并将新组合腾出到上方开放区域，再按本版试装情况拆取；没有重新检查的连续抽出路径不列为已验证。
- 整腿：先恢复空机架及机内工具通道，承托待拆腿，按110/165 mm两姿态反向拆四组M4。设备满装、封壳状态不作为直接拆腿条件。

本文件给出零件和接线依赖形成的装配顺序。刚体碰撞检查、工具路径检查和实际手工试装是不同证据；跳跃冲击、转换器热量、PETG长期蠕变及真实线束耐久仍需样机试验。

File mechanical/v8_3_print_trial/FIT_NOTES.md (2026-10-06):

# V8.3 首台打印试装说明

本审查覆盖 V8.2 继承的 **38 类定制零件、77 件**。其中原打印件 14 类/15 件，原金属件 24 类/62 件均可输出名义形状供观察；这不表示每个精密件都能用 0.4 mm 喷嘴直接打印到最终公差。V8.3 改动的外壳以新版 STL、打印清单和几何检查为准，本表中的原编号用于追溯。

**这套全塑料样件仅用于断电、独立支承下的手动试装。不用于承重、通电行走、旋转轮胎或跳跃。** 已有电机与电子模块用实物试装，不再购买或打印设备占位件；轴承、螺钉、螺母、标准垫片仍使用真实标准件。

## 打印与后处理原则

- 默认 220×220×250 mm、0.4 mm 喷嘴、PETG。按毫米、100% 比例导入；不要整体缩放，也不要为让两件拼上而整体扩孔补偿。
- 首轮建议主体 0.20 mm 层高、3～4 道周壁、20～30% 填充；叉耳和紧固孔附近可用局部实心。它们是试装起点，不是承载配方。温度/冷却采用实际材料与打印机的已验证 PETG 配置。
- 销、衬套、薄盖优先单独打印，100%实心；LC05 必须按0.20 mm总厚切片。支撑接触面和象脚需清理，但不将配合台阶磨平。
- STL 的网格闭合或能放入打印机，不等于切片中保留了全部薄片/小孔。打印前逐层查看 LC01～LC06、小螺母穴、悬空叉耳、壳内横梁和插槽。
- 现有 CAD 多以光滑底孔表示待攻螺纹。M2/M3 小牙不要假定已经打印出来；必要时清孔后手工攻牙，禁止以金属件装配扭矩锁紧塑料牙。盲孔加工不得超出原有效深度。
- 通孔可按原图清理；轴承/止口/轴销孔先量实物再处理，禁止将所有Ø3孔一律钻成3 mm，原孔可能是螺纹底孔或不同配合。轴承外圈必须就近支承，不敲击滚动体。
- 每处修磨记录“原打印实测尺寸、去除量、最终尺寸”。修磨后能安装，只说明试装可以继续，不能反推原金属公差已验证。

Prusa 官方说明，0.4 mm 喷嘴常见挤出线宽约0.45 mm，悬垂支撑面质量和配合精度取决于工艺；不能把金属件0.005～0.05 mm级要求视为FDM可直接达到。[原厂设计指南](https://help.prusa3d.com/article/modeling-with-3d-printing-in-mind_164135)；[层高指南](https://help.prusa3d.com/article/layers-and-perimeters_1748)；[PETG指南](https://help.prusa3d.com/article/petg_2059)。

## 先打这些接口，避免一次打完整机再返工

1. **微型件首件**：LC01×1、LC02×1、LC03×1、LC04×1、LC05×2、LC06×1。配一只实物626ZZ1及真实M2螺钉，确认薄片能取下、小孔可清理、肩台阶仍在。LC05保留同厚片材备选。
2. **髋/膝套接**：P18×1、P19×1，配真实J4310和3根Ø4定位销。先干装定位圆面，再检查螺钉能否按顺序进入；不强压三个销。
3. **一侧完整嵌套腿**：P21、P23、P25、P26、P27各1件，配一侧的3套轴承/销套/压盖（每种LC01～LC04各3、LC05×6、LC06×1）。顺序为OB内框→OA→OB外包壳，再由CW的B轴承与OB双侧嵌入组合，并装AC两端；装一轴转一轴，不同时锁紧全部轴。
4. **机架与电子模块**：P01×1、P02×1、P03×1、P04×2，随后P10/P11/P12/P14/P30。已有Jetson、USB2CAN裸板、配电板、转换器都先在机外完成支架预装。
5. **前脸、后盖和全套外壳**：用新版前脸配实际5寸屏/D435；后盖配真实USB拓展坞和线缆；确认接口能插拔、充电口可换板有操作空间后，再完成另一侧腿和其余件。所有重件由桌面/治具支承。

## 逐项限制与处理

数量是整台机器人净用量；左右通用件按数量打印，左右不同件保留独立编号。

|编号|名称|数量|重点限制|试装建议|
|---|---|---:|---|---|
|P01|机架底板|1|大平面翘曲、沉孔/螺纹孔|承力底板平面向下；测四角及装配面平整度，螺孔逐孔清理。支承整机时用独立治具，不能由塑料底板承担原机载荷。|
|P02|右承力侧框|1|侧框跨距、横向孔与螺纹|最大平面朝下优先；轴孔/沉头孔支撑须清理，禁止靠螺钉强拉翘曲框架。|
|P03|左承力侧框|1|侧框跨距、横向孔与螺纹|同 P02；左右分开编号，核对髋座安装方向。|
|P04|前后通用横框|2|8 mm 厚框、大开口与螺孔|宽面向下；通用件打印 2 个，先与 P01/P02/P03 在平板上干装。|
|P05|前主壳|1|V8.3 新版外壳尺寸/方向与打印验证报告为准；大壳支撑/翘曲|本项只继承原编号和配合注意事项，打印尺寸/方向必须以 V8.3 最终导出和验证为准；开关孔、前脸、肩罩与机架连接面不得残留支撑。|
|P06|后检修壳|1|V8.3 新版外壳尺寸/方向与打印验证报告为准；后接口/托架|以 V8.3 最终导出为准；先装真实扩展坞及插头，再试装后壳；不得为了闭壳压折线缆。|
|P07|屏幕相机前脸板|1|3 mm 薄面板，屏幕及相机窗口|后安装平面落床，相机凸圈向上；清理象脚和孔边；在既有屏幕/相机上仅轻放，不强压玻璃或镜头。若 V8.3 更新本件，以新版为准。|
|P08|左右通用肩罩|2|环口、悬空曲面与薄边|可按原环形端面落床；2 个通用件，检验左右电机包络及运动范围，不强扣电机。若 V8.3 更新肩罩，以新版为准。|
|P09|电池托|1|薄底、耳片及束带槽|底面向下，耳下局部支撑；用已有电池断电试装，先清理底座槽和束带槽；不得用电池重量试验打印腿承重。|
|P10|电器托盘|1|3 mm 托盘、窄穿槽与后边走线 U 槽|大平面向下，完整打印后再清孔；安装架穿槽、USB 线槽不可被首层象脚封死。|
|P11|Jetson右夹座|1|夹口及9.4 mm局部高度|平面向下；先检查已有 Jetson 原底座能自然贴合，不用螺钉强压 PCB。|
|P12|Jetson左夹座|1|夹口及9.4 mm局部高度|同 P11，左右夹座不能互换编号。|
|P13|D435一体后座|1|相机固定孔、后座悬空结构|按支承面落床，镜头/USB 插座附近清除全部支撑；不以螺钉拉偏相机。|
|P14|IMU刚性安装桥|1|143 mm跨距、IMU定位桥刚度|先查 IMU 原点仍位于设计中心，再查两端孔；打印桥只验证位置，不能证明金属桥的振动/刚度表现。|
|P15|屏幕右托夹|1|托夹凹口及17.5 mm侧壁|清理屏幕托面；保留既定 0.5 mm 软垫，不通过拧紧来补偿夹口尺寸错误。|
|P16|屏幕左托夹|1|托夹凹口及17.5 mm侧壁|同 P15。|
|P17|左右通用髋定子座|2|电机安装圆面、沉头孔|平面落床，校验 6 个电机孔和机身 4 孔同时对合；只轻拧已有金属标准螺钉。|
|P18|左右通用髋转子法兰|2|Ø43 套接及三定位销，原直径余隙0.050～0.080|与 P19/P20 先打印配套；不整体缩放，不强压 Ø4 钢定位销。局部轻磨并记录实际去除量只能确认能装入，不能证明原金属公差可行。|
|P19|右膝定子套杯|1|Ø43.05 母止口/7 mm嵌合、径向M3锁紧|杯口朝上优先；四侧螺孔为名义底孔，清孔后手工攻牙；塑料牙仅轻拧，不测试锁紧扭矩。|
|P20|左膝定子套杯|1|同 P19，左侧方向|同 P19；保留左/右型号，不能镜像切片代替确认过的零件。|
|P21|右OB内框|1|OB内框D50嵌套、2～4 mm局部面、B点Ø8套孔|宽面朝下，保护 D50 止口和 B 孔同轴；与 P23 成对编号。需用实际钢轴轻推验证，禁止用螺钉把两片拉到同轴。|
|P22|左OB内框|1|OB内框D50嵌套、B点Ø8套孔|同 P21，与 P24 配对。|
|P23|右OB外包主臂|1|包壳深腔/3 mm前皮、D50.2/D35.4导向孔与M3底孔|开腔朝上优先，局部支撑不可粘伤嵌套面；先检 OA 能手动全程摆动，再装止位销。支撑清理、缩孔都可能造成假干涉。|
|P24|左OB外包主臂|1|包壳深腔、D50.2/D35.4导向孔|同 P23，与 P22 配对。|
|P25|左右通用OA曲柄|2|3 mm双叉耳、9 mm叉内距、Ø8套孔、Ø35鼻|叉耳不适合硬撬；插入 AC 和轴承后确认两肩/轴承不被夹紧。0.05 mm 设计轴向间隙不能以 FDM 装配阻尼验收。|
|P26|左右通用AC轴承连杆|2|两个Ø19轴承座、0.05 mm压盖名义轴向余隙、M2底孔|宽面落床且轴承座尽量朝上；轴承需手推/轻滑入，支撑座底清理后测深；只通过压盖挡住外圈，不用螺钉压入轴承。|
|P27|右CW下臂|1|CW的B轴承座/C双叉、3 mm耳、轮电机面|宽面优先落床并局部支撑叉耳；按B点轴承在CW内、OB从两侧嵌入的顺序试装；禁止先锁死再强行对孔。|
|P28|左CW下臂|1|同 P27，左侧方向|同 P27。|
|P29|通用轮辋|2|轮辋Ø33.05定位止口与原厂Ø33，直径余隙0.03～0.07|轴线竖直；6 孔同时自然对合且轮辋端面贴合，实际轮胎仅作外形试装；不能旋转做动平衡/高速试验。|
|LC01|轴承外圈压盖|6|0.8 mm压盖/3-Ø2.2孔，约4层@0.2|平放并100%实心，先打1件；去毛刺不磨薄，螺钉头只轻触。可用同厚0.8 mm片料按同轮廓制作；不能擅自加厚。|
|LC02|双端内螺纹关节轴销|6|Ø6×14.05轴销、两端Ø1.6底孔/M2×0.4|轴向竖直先打1件且100%实心；STL无真实螺旋牙，需清理1.6 mm底孔并手工攻M2；极易滑牙/折断，不验证销的抗剪或精度。无牙Ø6金属光杆只可临时对轴，不等效于带双端防脱结构。|
|LC03|内侧一体带肩衬套|6|Ø8/Ø6.05套段壁0.975、Ø8.4肩单边凸0.2、总长3.75|大肩落床且100%实心，细层高0.10～0.15；0.2 mm是径向凸缘量，不是独立薄壁。首层象脚会吃掉小台阶，打印只能检位置，不能检0.005～0.010过盈。需实测端肩长度。|
|LC04|外侧一体带肩衬套|6|同LC03；肩1.70、总长4.20，名义轴向余隙0.05|大肩落床且100%实心，细层高0.10～0.15；量总长并轻磨端面，不让肩顶密封盖。不得把肩磨短后仍宣称验证了原名义余隙。|
|LC05|轴销薄防脱挡片|12|Ø9/Ø2.2×0.20，实际总厚只有1层@0.2|平放，首层精确0.20 mm、100%实心，单独打印先看切片保留；难以完整取下，建议同时备0.20 mm PET片或金属精密片按同轮廓裁切。禁止加厚为0.8/1 mm或换普通M2垫圈，否则改变轴向堆叠。|
|LC06|OA装配限位肩销|2|M3×3外螺纹、Ø4肩4.2、Ø7×1头及0.8槽|肩轴线竖直，100%实心；名义CAD外圆不含真实螺旋牙，不能直接旋入M3底孔。塑料件可先作限位位置观察；若确需旋入须按同尺寸加工真实外牙，通用M3螺钉头和肩未必可替代。|
|P30|配电通信一体安装架|1|集成支架悬空横梁、M1.6裸板小孔/螺母穴|局部支撑避免堵住M1.6、M2.5孔和侧向取螺母口；先机外装已有裸板/配电板/转换器再入托盘；严禁让支撑残料顶元件。|
|P31|背部USB扩展坞压托|1|USB压托两端螺孔/柱间隙、0.5 mm软垫|按座面落床，配后壳和真实扩展坞试装，软垫不可随意增厚以免压变USB外壳。|
|P32|后充电口可换安装板|1|2.5 mm薄板、中央Ø3导孔|平放；中央孔只是待选DC母座的导孔，不是可直接装5.5×2.1母座的最终开孔。保留此件可替换，实物母座确定后再扩孔。|

## 不能按“装得上”判定的精密配合

|配合|原金属设计目标|塑料样件能确认的内容|
|---|---|---|
|髋法兰Ø43/Ø43.05|直径余隙0.050～0.080 mm|同轴关系、插入方向、7 mm嵌合和侧向螺钉可达性；不能确认真实过渡配合或传扭|
|轴销Ø6/轴承内孔|间隙0.003～0.010 mm|孔位能否对齐；精磨轴验收仍需金属件和实物轴承|
|衬套Ø8/叉耳孔|轻过盈0.005～0.010 mm|双叉嵌套关系、两肩方向；PETG需避免压装开裂|
|双叉轴向叠层|名义9.00−1.25−6.00−1.70=0.05 mm|台阶/轴承装配顺序；打印阻尼不能替代金属游隙测量|
|Ø6销长14.05/支承跨距14.00|防夹死余量0.03～0.07 mm|两端挡片空间和螺钉工具可达性；塑料挠曲可掩盖夹死|
|OB D50/D50.2及OA鼻Ø35/D35.4|同轴嵌套、侧开口允许OA转动|全程手动包络/干涉；不能证实定位刚度|
|轮辋Ø33.05/轮电机Ø33|直径余隙0.03～0.07 mm|孔阵列与轴向装配关系；不证明端跳/动平衡|

## 难打印件的同尺寸替代边界

- **LC05×12**：首选保留0.20 mm名义STL尝试单层；失败时用0.20 mm PET片（仅试装）或精密金属薄片，按Ø9/Ø2.2裁切。更换材料不改总厚，不用普通M2垫圈叠凑。
- **LC01×6**：0.8 mm PETG薄盖可做轻拧试装；如翘曲严重，可用同厚0.8 mm片料按原孔阵列制作。
- **LC02×6**：Ø6光杆可临时验同轴，但缺少双端M2螺纹，不能计为等效正式轴销或防脱检验。若需完整防脱装配，最终仍须同尺寸双端M2件；本阶段先用打印样件观察并手持防落。
- **LC03/LC04各6**：小台阶能够成形，但不可用打印件证明微米级压配或0.05 mm游隙；如必须量化精配，需同尺寸车削铜套。该项目不是本次“标准件采购”强制项。
- **LC06×2**：普通M3螺钉的头、肩不等同本件。打印名义轮廓可判断限位位置，缺真实外牙时不得硬拧进入OA。

本说明未修改任何名义零件或原V8.2文件；未进行材料强度、寿命、落地冲击或真实G-code验证。全部标准件数量由本次采购BOM统一管理。

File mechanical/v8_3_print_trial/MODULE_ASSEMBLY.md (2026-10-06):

# V8.3 打印试装的模块安装顺序（继承 V8.2）

> 打印试装包说明：本文继承历史装配关系；金属工艺、载荷和已通过的检查均只适用于原注明版本。全塑料样件以 [FIT_NOTES.md](FIT_NOTES.md) 为先，须断电并由独立治具支承，不能照金属工艺强压、强拧或通电。V8.3新版外壳尺寸、打印方向及验证状态以最终打印清单/报告为准。

先装两腿与空机架，再装电池，随后放入机外预装的电子盘/配电通信模块，最后接入前脸与后盖模块。外壳不承担腿部主载荷。+X朝前，+Z向上；从背部看右侧为−Y。

本版保留V8.1腿部几何和紧固关系。腿部内部工艺仍见[基线腿部装配](baseline_v81/LEG_ASSEMBLY.md)和[基线公差](baseline_v81/LEG_FITS.md)。下文更新电器模块及外壳安装，不能用旧版“完整电子盘先抬4 mm再后抽”的检查直接证明本版新增竖板也能走同一路径。

## 模块分工

|CAD分组|预装内容|安装依赖|
|---|---|---|
|M01/M02|左右整腿、电机、轴承销套及轮组|先接空M03，四颗髋座M4预先放入|
|M03|金属底板、左右髋框、前后横框|保留电器仓空置供腿部螺母和工具操作|
|M04|电池/窄托、Jetson/PETG电子盘、IMU桥|电池先装；电子盘与M07可在机外组合|
|M05|5寸屏、D435及前脸|线缆预接好，再封前脸|
|M06|前主壳、后盖、肩罩、开关、后接口夹持件|开关随前壳预装；后盖同M08机外组合|
|M07|裸USB2CAN、用户分配PCB、24→19 V模块及一体PETG支架|先机外装板和模块，再以4颗M3×12安装到电子盘|
|M08|四口USB扩展坞及连接线|随后盖装入；夹具/盖的CAD对象仍归M06，不重复计数|

原 V8.2 完整工程中的模块 STEP 保留共同坐标；本打印包不附大体积模块 STEP，使用本包逐件 STL 和下方内部标注图核对。模块分组是装配层级，并不等于每组都能独立无条件抽出。

## 机外预装

1. **左右腿。** 沿用髋座和髋电机→两件髋膝法兰及膝电机→OB内座→从同轴开口装OA→AC/CW轴承与销套→OB外罩→限位销→轮组的顺序。髋座仍裸露时预放每侧4颗DIN7991 M4×12，临时防掉。不能把Ø3.2工具可通过当作Ø8螺钉头也能后装通过。
2. **电池模块。** E626S含磁底按85.6X×44.5Y×61.6Z放入窄托，DC侧朝上；离机穿好两条束带。底部仅一层、厚≤1 mm，搭接移到顶上并避开实际插头。电池400 g仍是含附件质量预算。详见[基线电池安装](baseline_v81/BATTERY.md)。
3. **M07服务支架。** 支架是一件PETG结构，USB2CAN平放、Type-C朝−Y；用户PCB竖装，PCB面约X66，范围Y5..37、Z−13..26 mm，DC口朝+Z。转换器放在−Y侧支臂上。裸CAN用4颗M1.6×10和配套螺母；PCB用4颗M2.5×12及配套螺母，直接使用核对过包络的螺钉头，不任意加入大直径垫片挤压板上元件；转换器用2颗M3×8及螺母。型号/长度以最终BOM为准。
4. **电子盘组合。** 在台面上托住电子盘，让M07竖背板X60..63穿过盘上3.6 mm槽。4颗M3×12从上方穿入，螺母由盘下安装，中心为X49/62、Y−30/+47 mm。先完成这些盘下螺母，再装入机身。Jetson继续使用原底座和原托夹；各面向+X的USB、Type-C、DP与电源线先插好、留应力释放，避免封前脸后再盲插。盘后缘X−75/Y25有7 mm宽U形开口槽，扩展坞不可拆线从开口侧放入，不要求模塑USB插头穿过圆孔。服务架X70/Y21的Ø8.6孔用于穿线；其中央腿束通道加宽为10 mm，范围X48..77/Y−5..5/Z36..38，不改变4个安装点。实际插头和整束净空需分别核对。
5. **顶部开关。** 前壳顶孔Ø16.3，壁厚3 mm；开关轴心X60/Y0，外法兰在顶面，AF19螺母由壳内旋紧，再接插座。图示插座组合总深47.5 mm，不能只按35 mm裸开关判断空间。开关DC触点与LED电压尚未确认，装上不代表可以通电测试整机负载。
6. **后盖与扩展坞。** 四口朝−X，从后盖内部放入104×30×10 mm坞体；左右保持边和底托定位，再装一件压托，以2颗M3×16及螺母固定。耳座X−56/Y±47，后盖预装结构最大横宽109 mm，可与原后框116 mm开口比较；仍需对实际插头和线束试装。两片2×15×0.5 mm软垫放在坞顶X−63..−61、Y中心±35、Z10..10.5，压非端口壳边，不靠插座固定。
7. **充电接口板。** 位于背视右下，中心Y−46/Z−25 mm；可换片以2颗M3×10及螺母固定。片中Ø3仅定位导孔，不能直接安装DC母座。按最终母座开孔图扩孔或重打；插合5.5×2.1 mm不能当作面板孔径。
8. **前脸。** 屏幕/D435沿用V8.1安装；屏幕USB和HDMI均先接好，相机用USB3数据线。DP→HDMI转换必须包含在视频连接内，Jetson USB-C不能直接输出画面。

## 整机总装顺序

1. 预装空金属机架，电器模块及机壳暂不放入。两腿以180 mm髋轮距、Beta=0°轴向靠入，髋座四颗预放M4穿过机架孔，从机内放入M4垫片与螺母。
2. 四颗髋座螺钉不能在同一姿态全用直工具锁紧。后上X−30/Z+30在110 mm腿长处理；其余三颗在165 mm处理，Beta均为0°。移开工具后才调整姿态。外侧AF2.5直内六角杆Ø≤3.2，内侧AF7薄壁套筒外径≤10.5；详见[基线工具与两腿装配记录](baseline_v81/MODULE_ASSEMBLY.md)。
3. 恢复180 mm腿长。先放入完整电池/托盘模块，4颗M3×8从顶部固定。此时上方电子盘、IMU、前脸均未占据安装路径。
4. 将机外预装的Jetson电子盘+M07组合从上方对准安装；竖PCB随盘进入前下方空隙。不得以板上连接器顶靠电池托或前框。电子盘原4颗M3×8紧固点X−74/+38、Y±48保持不变。实际组合落装路径须在无电状态试装，不能把V8.1只带Jetson的连续扫掠结果移用到新增竖板。
5. 安装IMU桥及HI13R2，保持名义原点(0,0,85) mm和原轴向；线缆留柔性弯曲，不把线束绷紧到传感器。
6. 先将电池、分线及主开关相关线束接到可操作位置，再装前主壳。电池至顶部经过托盘Ø10过线孔；两侧腿束从机壳X89/Z54的Ø10孔引出。三处均按3 mm板厚选护线套，实际净孔要求至少7 mm，并核对带插头线束能否穿入。
7. 前脸用支架/台面承托，连接相机USB、屏幕USB与HDMI，检查前部短插头区域后锁前脸。各主机端口已按正/负Y上下层分配，详见[ELECTRICAL_INTEGRATION.md](ELECTRICAL_INTEGRATION.md)。
8. 扩展坞原150 mm线经电子盘后缘7 mm宽U形槽侧向放入，再用250 mm USB3 A公母延长线接Jetson正Y座上口，沿正Y侧高位路径绕行；接合点和多余线长绑在可拆卸服务位置。槽边清除打印毛刺，不将线缆压在盖板接缝中，也不强推模塑插头穿孔。后盖充电支路接在主开关前。接完后盖相关插头，再将完整后盖就位锁4颗M3×12；不得靠线缆悬挂盖板。
9. 理顺两腿弯折线环与固定端，最后装肩罩。先断电手动走完全腿行程，观察轮胎、OB/OA包夹槽和限位附近是否夹线。电气首次上电前核对极性、配电板线序、两路CAN终端及转换器输出。

## 走线图的边界

原 V8.2 FreeCAD 的“走线路径预留”组和走线参考 STEP（本打印包不附）是空间走廊，材料标签为`routing_allowance`；它们不进入实物装配STEP/STL、采购数或零件质量。球/圆柱折线不是线缆实际弯曲形状，路径端点是连接区域，不是确认过的插头接触端面。

`routing_allowances.json`列中心线长度、占位半径和端点；[V8.2历史路由检查](routing_validation.json)中的`all_clear`仅针对所列预留几何。[V8.2历史结构检查](electrical_final_validation.json)与[V8.2内部标注图](previews/internal_structure_annotated.png)供未改动内部布置核对；这些文件不证明V8.3最新外壳已通过检查。最终选线还需考虑插头外壳、插拔行程、最小弯曲半径、服务余量及动态寿命；不能把折线长度直接当下料长度。线路分组表示动力、USB、视频和CAN功能关系，PCB内部网络和引脚不能由STEP推断。

## 拆卸维修

- 后盖：断开电池，拆后盖螺钉并用台面承托，拔扩展坞延长线接头与充电支路，再取下盖板。盖内可独立换扩展坞、压托、软垫和DC接口小板。
- 配电/通信：先断电、拆前脸/必要机壳，释放USB/电源/左右腿接头。服务架与电子盘之间的螺母在盘下；本版按机外组合维修设计，不承诺所有螺母可封壳盲拆。需要时连电子盘一起取出，在台面拆M07。
- 电池：先移开IMU桥和挡住向上通道的电子盘/M07、前脸及壳体，断开电池线，再拆4颗托盘M3×8，电池与托盘完整向上取出。无需拆腿，但不能从封闭后壳直接抽电池。
- Jetson：新增M07竖板改变电子盘包络，旧版“上抬4 mm后抽180 mm”的路径仅为历史证据。优先释放线缆并将新组合腾出到上方开放区域，再按本版试装情况拆取；没有重新检查的连续抽出路径不列为已验证。
- 整腿：先恢复空机架及机内工具通道，承托待拆腿，按110/165 mm两姿态反向拆四组M4。设备满装、封壳状态不作为直接拆腿条件。

本文件给出零件和接线依赖形成的装配顺序。刚体碰撞检查、工具路径检查和实际手工试装是不同证据；跳跃冲击、转换器热量、PETG长期蠕变及真实线束耐久仍需样机试验。

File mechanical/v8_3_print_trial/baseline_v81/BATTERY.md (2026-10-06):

# WHEELTEC电池与一体托盘

> 打印试装包说明：本文继承历史装配关系；金属工艺、载荷和已通过的检查均只适用于原注明版本。全塑料样件以 [FIT_NOTES.md](../FIT_NOTES.md) 为先，须断电并由独立治具支承，不能照金属工艺强压、强拧或通电。V8.3新版外壳尺寸、打印方向及验证状态以最终打印清单/报告为准。

按用户图纸采用本体85.6×61.6×42 mm、含磁吸底座总厚44.5 mm。CAD仅建立包含底座的保守长方体外廓，不推断磁铁、内部电芯或未标注的DC孔位。用户已明确选择24 V等级的E626S（标称22.2 V、满电25.2 V）；型号选择依据为用户确认加官方表格，淘宝SKU页面尚未直接读取。整包含底座质量继续用400 g预算，官方337 g是否含磁底未说明，不能当作本次装配实测重量。

安装为85.6沿X、44.5沿Y、61.6沿Z；范围X±42.8、Y±22.25、Z−43.8～17.8 mm。DC所在窄侧面朝上。腿部、电机、金属机架、机壳、Jetson位置不变。

托盘为一个PETG零件，保留原4个X±70/Y±20的M3×8固定点，耳座Z−39～−36，底厚2.4 mm；承托面Z−43.8。主托宽49.5 mm，长侧壁2 mm，电池每侧留0.5 mm装配间隙。底板现有中央凹台上表面是Z−48，托底Z−46.2，实际名义间隙1.8 mm，不按外围底板高度误判。

两条现有宽≤10 mm束带在X±24穿过一体侧窗口，再绕托盘底部和电池形成完整闭环。按厚1 mm带材、保守外接矩形中心线，闭环长231 mm；再留至少50 mm顶部搭接，建议采购两条10×300 mm无厚大扣头的可修整束带，试装后裁剪。侧窗宽12 mm、上方保留4 mm桥；下方只允许厚≤1.0 mm的单层带材，折返和搭接置于电池上方，且不可占用实物DC插头与线材位置。底部1 mm带材之后剩0.8 mm名义间隙。普通厚魔术贴或扣头未必适用，实际DC位置也可能要求调整穿带位置；本版不虚构二者兼容性。机械止挡与束带承担约束，磁吸只辅助定位，不能凭磁吸宣称承受跳跃冲击。

电池顶到电器盘底共12.2 mm。因为DC孔没有定位尺寸，本版对整个顶面保留11 mm高的设计检查区，最高Z28.8，离电器盘底Z30为1.2 mm；这不是已选插头模型。必须实测弯头外伸、线径和弯曲半径，并确认束带不会压在插头上。超出该高度的插头不能直接宣称适配。

保留单托盘、两条束带、4颗M3×8，BOM件数不增加。托底朝下打印，一体抬高耳座下方使用可清除支撑；12 mm侧窗口及4 mm桥打印后应清理、通带，避免锐边割带。是否能在两腿装好后整体装拆，由battery_local_review.json与模块装配审查约束；装电池前应断开所有输出，避免金属工具搭接端口。工艺间隙是样机起点，打印试装、束带拉拔、振动和跳跃保持力仍需试验。

[官方24-DC规格书](https://wheeltec.net/24-DC.pdf)第12页已选E626S：标称22.2 V、2550 mAh、337 g、持续6 A、瞬时13 A，瞬时时间未给；满电25.2 V、截止18 V。第9页磁吸座用于机械固定；DC5.5×2.1为充放同口。参数不能直接证明所有电机可持续使用或跳跃供电能力，仍需按真实负载/BMS/连接器复核。

选型审查附注：12 V等级E351S也采用相同外形，单靠尺寸不能区分电压；本次由用户明确确认E626S后消除此选型歧义。淘宝SKU页面未直接读取，包装是否含磁底、官方337 g范围、DC极性与实物弯头尺寸仍待核实。此附注更新选型信息；冻结CAD源中的“candidate”是确认前记录，几何和检查哈希不变，以本说明和battery_interface.json为最终型号依据。

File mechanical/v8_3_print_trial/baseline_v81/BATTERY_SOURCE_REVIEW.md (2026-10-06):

# 电池来源与接口核对

> 打印试装包说明：本文继承历史装配关系；金属工艺、载荷和已通过的检查均只适用于原注明版本。全塑料样件以 [FIT_NOTES.md](../FIT_NOTES.md) 为先，须断电并由独立治具支承，不能照金属工艺强压、强拧或通电。V8.3新版外壳尺寸、打印方向及验证状态以最终打印清单/报告为准。

核对日期：2026-09-28。用户商品链接的 item 为 `652194595520`、SKU 为 `5811076916462`。指定淘宝页面未读取成功，浏览器另被站点安全策略阻止访问；未登录、未购买、未绕过限制。因此**没有从网页确认该 SKU 的商品名称及套装内容**。随后用户明确确认选用 **24V 等级 E626S（标称22.2V、满充25.2V）**；本版选型依据为用户确认和厂家参数，仍不冒称网页已读取。

用户图纸的 **85.6×61.6×42 mm** 与厂家 **E626S** 一致，但同外形还用于 **12V 等级 E351S**，不能从外形或电机电压推断电池电压。E626S 现由用户另行确认，E351S 仅作型号歧义对照，不计入本机质量或电源参数。没有沿用其他型号 P760S 的6000mAh、15A或XT60参数。

来源为 WHEELTEC 官网[下载中心](https://wheeltec.net/down/class/index.php?catid=2&page=%7Bpage%7D)提供的[《24V安全锂电池手册》](https://wheeltec.net/24-DC.pdf)。本地原件位于 `source/battery/WHEELTEC_24V_manual.pdf`；PDF 共14页，以下页码为文件物理页码。元数据显示2025-01-16修改，但文档没有据此可确认的印刷版号。

## 用户已确认选型：官方 E626S 参数（第12页）

| 项目 | 官方表格内容 | 当前适用边界 |
|---|---|---|
| 外形 | 85.6×61.6×42 mm | 与用户图纸本体三维尺寸精确匹配 |
| 重量 | 337 g | **是否含磁吸底座未说明**；不能当作整套安装质量 |
| 电池组 | 22.2 V、2550 mAh | 商品称24 V电压等级，不能把24 V写成实际标称电压 |
| 容量下限 | 2500 mAh | 不据此推算整机实测续航 |
| 满充 / 截止 | 25.2 V / 18 V | 需与驱动器和电源转换输入范围匹配 |
| 最大持续放电 | 6 A | 用户确认E626S；实物标签与到货内容仍需核对 |
| 最大瞬时放电 | 13 A | 未给出允许脉冲持续时间或占空比 |
| 建议充电 | 1 A | 不作为电机制动回充许可的依据 |
| 插头 | **DC5.5-2.1 母头，充放电同口** | 并非仅充电口；未标注极性、配套公头外形和额定电流 |
| 电芯 / 外壳 | 三元锂 / 塑料 | 不套用同手册其他磷酸铁锂型号的数据 |

当前质量预算仍保留 **400 g**，作为电池、磁底和未核附件的工程预算；337 g 是手册电池条目的重量，400 g 不是厂家声明。电池能否支撑整机连续运行及跳跃，应由实际负载、电源损耗、脉冲时长和BMS保护共同判断，不能仅凭“24V”或瞬时13A做保证。

## 同外形型号核对记录

官网另一份[《12V安全锂电池手册》](https://wheeltec.net/12-DC.pdf)物理第11页的E351S也为85.6×61.6×42 mm。本地原件为 `source/battery/WHEELTEC_12V_comparison_manual.pdf`，页面证据为 `source/battery/official_12V_manual_page_11.png`。该型号标称10.8V、满充12.6V、截止9V、5100mAh、377g、持续8A/瞬时15A。**它不是本次选型**；这一对照说明为什么不能仅凭图纸或未读取的SKU链接断言24V。用户明确确认E626S后，才可把24V手册的参数用于本机供电分析。

## 用户图纸与连接器朝向

用户原图已保存为 `source/battery/user_battery_dimension_drawing.png`。图中单位为mm，电池本体厚42，含磁底厚44.5，因此磁底增加厚度2.5；图纸未给制造公差。

- 2.1 DC口画在 **85.6×42 mm的侧面**，接口轴线沿61.6 mm尺寸方向。
- 接口靠85.6长度的一端，并更靠磁底一侧；**图中没有孔心坐标、插头插入深度或公头外形尺寸**，不能把按像素估出的坐标当加工依据。
- 磁底在85.6×61.6大面背侧。按85.6X×44.5Y×61.6Z摆放，可使DC所在侧面朝上；此时磁底位于Y方向侧面。
- 顶部11 mm仅是待选弯头/线缆的设计占位，尚未证实实际公头和弯曲半径能够放入。应在确认孔心前保留该侧面的可达空间，不在未知坐标上画假孔或虚构电气触点。

## 磁吸底座：官方第9页

厂家描述的是**磁吸机械固定加底部限位块**；钢铁表面可直接吸附，铝合金或塑料表面可配背胶导磁片。手册没有给固定孔阵列、孔径、导磁片尺寸、吸附力额定值或跳跃冲击能力，也没有将磁底描述为供电触点接口。不能据此设计弹针供电。

第9页还明确限制磁吸吊装。样机的束带或刚性防脱结构应承担正向约束；本版不把磁吸独自作为跳跃载荷下的保持机构。用户图纸与手册均标有磁底专利号202420584730.X，但专利号不能替代安装尺寸图。

仍需供应商或实物确认：到货标签与用户确认的E626S一致、SKU套装配件、337 g是否含磁底、磁底孔槽、DC极性及公头包络、13 A脉冲时长、保护复位方式与制动回充限制。机械建模可以先使用已给尺寸，采购定版与电流能力判断保留上述边界。

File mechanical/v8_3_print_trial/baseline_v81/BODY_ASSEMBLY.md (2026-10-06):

# V8.1 机身模块、标准件与装配

> 打印试装包说明：本文继承历史装配关系；金属工艺、载荷和已通过的检查均只适用于原注明版本。全塑料样件以 [FIT_NOTES.md](../FIT_NOTES.md) 为先，须断电并由独立治具支承，不能照金属工艺强压、强拧或通电。V8.3新版外壳尺寸、打印方向及验证状态以最终打印清单/报告为准。

适用1台样机。外轮廓211×164×155 mm、R5、屏幕/相机/Jetson/IMU坐标继承V8；机身以下的腿杆长度、电机和轮组不变。本文件只涵盖M03～M06；左右腿及8套髋座M4总接合件由腿部BOM计数，不重复采购。

## 已落实的细节

| 位置 | V8.1改动 | 装配意义 |
|---|---|---|
| 屏幕后托 | 六角螺母承压肩移到X101，标准M3×20，螺母X98.6～101 | 取消M3×22及裁螺钉；设备与前脸位置不动 |
| 前/后壳到金属横框 | 前壳头座X92；后壳局部Ø6.4×2沉台，头座X−92；均M3×12 | 取消M3×14；夹持6 mm、名义入牙6 mm |
| D435后座 | 一体6 mm后横梁，M3×8名义入牙2 mm | 取消2个定制金属1 mm垫片与M3×6，未增加零件 |
| 主机托盘4颗M3×8 | 补上真实螺钉头并修改原托夹让位 | V8未建这些螺钉头，其与托夹相交；现X38为一体Ø11耳圈/Ø6.4孔，X−74为开口圆缺口并另留Ø3.4上方工具孔 |
| 机架紧固件 | 底板8、侧框8、电池托4、主机托4颗已补建 | 装配与BOM不再漏掉这24颗 |

D435默认25.05 mm深（原官方ROS模型），后面X91.95、支架背面X85.95；可选26.05 mm支架的后面X90.95、背面X84.95。两种均维持相机前面X117，使用同一M3×8、名义入牙2 mm。原工程的备用26.05 mm深相机支架 STEP（本打印包不附，需实测后另行选型）为**替换件**，一台只装一个支架，不能把备用支架加入净用量。先测实际相机深度，再选打印件。

## 模块化和装配顺序

1. **M03承力机架**：去毛刺、清洗、检查攻牙和轴线。前/后横框与左右侧框使用8颗DIN7991 M3×8；底板再用8颗同规格。按对角顺序轻紧、检查方正后完成锁紧。电器仓保持空置，先完成两腿接合；外壳保持拆开。新电池模块可在两腿连接后整体装入。
2. **M01左腿/M02右腿**：按腿部文件各自在工装上完成电机/法兰/连杆/轴承/轮组子装，确认关节活动与止挡方向。四颗髋座M4须在裸髋座时预放并临时防掉；整腿从两侧接入M03后再从机内放垫片和螺母。后上螺钉在髋轮距110 mm锁紧，另三颗在165 mm锁紧，不能宣称默认180 mm能直达全部四颗。电池模块/Jetson/IMU均不得先占用内侧AF7工具通道。具体见[模块总装顺序](MODULE_ASSEMBLY.md)；不用打印外壳承受腿载荷。
3. **M04-A完整电池模块**：按用户新图及确认的E626S选型，含磁底包络为85.6X×44.5Y×61.6Z，DC所在侧面朝上；质量仍保留400 g预算。离机把电池放入一体PETG托盘，穿好两条宽≤10 mm束带，托底仅允许厚≤1 mm单层，顶部搭接避开实际插头。整模块在髋轮距180 mm、Beta=0°时从上方落入完整双腿机架，再用4颗M3×8固定X±70/Y±20耳座。连续100 mm竖直路径和四条Ø3顶面工具通道均已通过，见`battery_local_review.json`；上方主机盘、IMU、前脸与外壳必须未装。该检查不包含未知插头、扣头及线束。托底名义间隙1.8 mm，1 mm带材后余0.8 mm；电池顶部11 mm接口占位距电器盘底另余1.2 mm，需要实测所选弯头。详见`BATTERY.md`、`BATTERY_SOURCE_REVIEW.md`。
4. **M04-B主机托盘**：在机外把完整NVIDIA原装套件放到托盘Z33；两件周边托夹用4颗M3×10、4片ISO7089 M3平垫、4颗ISO4032 M3螺母固定。螺母在托盘下方，先装妥再放入机架。将整块模块落到金属托架，用4颗M3×8从上方锁紧；新避让孔支持Ø3工具杆通道。不能把主机PCB夹作受力层。
5. **M04-C IMU桥**：机外用2颗M2.5×16、2颗M2.5普通螺母把HI13R2固定到金属桥，原点名义(X0,Y0,Z85)不变。再用4颗M3×8固定桥脚。选头径≤4.5 mm的光头圆柱内六角螺钉，勿把未经核对的滚花大头挤进原厂Ø4.6头部让位。IMU下不加未经验证的软垫。
6. **M06前壳**：装入前壳；通过尚未安装的整块前脸开口拧紧4颗M3×12到前横框。先放4颗前脸M3捕获螺母进后侧六角孔。此时仍能从机后整理线束。
7. **M05前脸模块**：机外完成屏幕+两角托+4片4×8×0.5软垫，4颗M3×20、4颗M3螺母；D435后座用2颗M3×8与设备连接，再用4颗M3×10、4颗M3螺母固定到前脸。确认屏幕小前挡只接触金属边、绝不压玻璃；未知金属边时须先实测修正止挡。接好电源/USB/HDMI并设置应力释放，再用4颗M3×12固定整块前脸。前脸重量应由台面承托，不悬挂在线缆上操作。
8. **M06后盖/肩罩**：完成电气与传感器检查、线束离开运动区域后，后盖4颗M3×12，肩罩总4颗M3×20。金属入牙不靠PETG打印螺纹；外壳与肩罩不属于跳跃主承力路径。

主机维修先断电、断开线缆并承托模块，移走两侧肩罩、后盖、后横框，以及对应12颗螺钉和4颗托盘M3×8，共16颗。Jetson、托盘、两件V8.1托夹及其12件紧固件保持子模块组装；先整体上抬4mm，再向后平移180mm。当前新电池、前脸及IMU在位时，两段平移的保守连续扫掠无干涉，抬升后相对髋电机名义竖向间隙1.5mm；在原高度直接后抽会碰到髋电机。后横框仅核对6个抽出位置，不把该部分宣称为连续路径验证；线缆/插头、手、自由工具运动及制造公差未验证。原始证据见[本版维修检查](maintenance_access_review.json)。重新装配后复查线束、止挡和传感器坐标标定。

## 制造分块与通用件

| 件组 | 建议工艺 | 合并原则 |
|---|---|---|
| 底板、左右髋侧框、前后横框 | 6061-T6 CNC，板材为毛坯，2.5D铣削+钻孔/攻牙；薄壁避免装夹变形 | 保持五件可拆承力骨架，不为一台样机强行重做钣金展开；侧框凸台不是普通平板激光切完即可替代 |
| HI13R2桥 | 6061-T6 CNC；夹持基准一次加工、跨桥平面保证 | 一件刚性桥，不拆成许多角码；不作打印替代 |
| 机壳前/后、整块前脸、肩罩 | PETG打印，外表面与分模缝保持V8 | 可拆大件，保留打印成形方向和220×220×250 mm成形限制 |
| 电池托、主机托、主机外围托夹、D435支架、屏幕角托 | PETG打印，非主承力安装件 | 摄像头后垫并入支架、主机避让耳并入托夹；左右屏托和主机托夹仍是必要手性件，不盲目合并 |

实际布尔差验证：前后横框绕Z轴180°可共用一个制造SKU（用量2）；左右肩罩同理共用一个SKU（用量2）。装配对象名称保留，制造合并依据见`manufacturing_aliases.json`。左右髋侧框有非对称托盘凸台，继续区分左右。

## 标准件与公差

机身共有**9个标准件SKU、82件净用量**，详见`body_hardware_bom.json`；另有4片软垫和2条电池带。整机BOM应再与腿件合并同规格，不能把这个机身小计当作整机总数。

- ISO4762钢8.8发黑：M3×8/10/12/20和M2.5×16。ISO4032螺母8级镀锌：M3 AF5.5/t2.4、M2.5 AF5/t2。ISO7089 M3平垫200 HV镀锌：Ø3.2/Ø7/t0.5。
- 沉头M3×8指定**Bossard BN20、DIN7991、010.9发黑，头Ø6/k1.7**。DIN7991与ISO10642不能笼统互换：所查ISO10642的M3头径上限6.72，可能不适合现有Ø6.4沉台。沉头长度包括头部，圆柱头长度从头下量。原料等级不能代替连接强度验证。
- M3通孔CAD名义Ø3.4；机加工装配孔建议验收Ø3.4 +0.10/0 mm。打印孔先做同方向试片，必要时打印后钻至该范围，勿用整件缩放补孔。
- 打印M3六角座CAD AF5.8，配螺母最大AF5.5，名义每边0.15 mm间隙；建议用AF5.7/5.8/5.9试片选料，再将孔补偿固定到切片工艺。用少量可移除点胶只作防掉，不把螺母胶粘强度算作承载能力。
- 屏角托侧间隙每侧0.5 mm，机壳舌槽单侧约0.3 mm、前脸周边每侧0.2 mm沿用V8，均是设计起点；PETG收缩、翘曲和打印方向须实测校准。壳体配合以手推就位，不可用螺钉强拉变形。
- 金属攻牙M3×0.5按6H验收；现有Ø2.5底孔不得直接当成已加工的内螺纹。5/6 mm是名义入牙长度，短盲孔要控制完整牙深、钻尖、攻牙导牙与螺钉长度公差，先试装确认不顶底。D435入牙上限3 mm来自厂家，名义2 mm的1 mm余量还要覆盖实际支架厚度和螺钉长度误差。
- 桥脚和金属安装平面可先以0.10 mm平面度作为样机图纸目标，配对孔位置以共同基准检验；这是设计目标，须由加工方确认能力，并非CAD已自动保证的公差。承力杆轴承座/配合公差以腿部文件为准。
- 不新增热熔螺母SKU。现有可拆塑料件使用捕获普通螺母或金属骨架内牙；若以后改热熔嵌件，需要按所选厂商嵌件外径/长度/PETG样件决定孔，不得把一种“通用M3孔径”套用所有嵌件。SPIROL指导要求嵌件孔比嵌件更深、避免螺钉顶底，但它没有给本样机PETG打印接头的承载认证。

所有螺钉扭矩需要按实际螺纹材料、润滑/锁固剂、连接受力和塑料蠕变验证确定；不把钢螺钉扭矩表直接应用到打印壳体或原厂小设备。模型证明的仅是名义几何与装配关系，未验证跳跃、振动、疲劳、散热或线束寿命。

## 资料依据

- [Bossard BN20](https://www.bossard.com/it-it/eshop/viti-normalizzate-con-manovra-interna/viti-a-testa-svasata-piana-con-esagono-incassato-interamente-filettate/p/20/)：DIN7991、010.9发黑及不能直接替代ISO10642的说明。
- [Böllhoff ISO10642尺寸表](https://eshop.boellhoff.de/out/media/pdf/ISO_10642_Stahl_8.8___de.pdf)：沉头范围区别。
- [Böllhoff ISO4032 8级螺母](https://eshop.boellhoff.de/out/media/pdf/ISO_4032_Stahl_8___en.pdf)：M3 AF/厚度上下限。
- [Aspen M3平垫](https://www.aspenfasteners.com/m3-din-125-type-a-iso-7089-7090-metric-standard-flat-washers-steel-zinc-plated/)：Ø3.2/Ø7/0.5尺寸范围。
- [SPIROL嵌件孔设计](https://www.spirol.com/resources/white-papers/how-to-design-the-proper-hole-for-heat-ultrasonic-inserts/)：热塑性嵌件需要指定孔型及材料验证。

更完整的尺寸参考链接、按连接位置展开数量、CAD对象名称和来源哈希见`body_hardware_bom.json`。资料页面用于尺寸/标准核对，未声称供应商已确认本机器人承载能力或指定国内库存。

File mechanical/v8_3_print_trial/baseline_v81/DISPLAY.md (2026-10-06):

# GK-HD 5寸屏与外壳托架

> 打印试装包说明：本文继承历史装配关系；金属工艺、载荷和已通过的检查均只适用于原注明版本。全塑料样件以 [FIT_NOTES.md](../FIT_NOTES.md) 为先，须断电并由独立治具支承，不能照金属工艺强压、强拧或通电。V8.3新版外壳尺寸、打印方向及验证状态以最终打印清单/报告为准。

用户选定新规格书中的5寸版本。厂家只确认外形 **122×78×14.5 mm**；PDF第2页给出尺寸，封面为GK-HD / V3 / 20240428。源文件与6页渲染保存在source/display。

| 项目 | 本版采用值与依据 |
|---|---|
| 屏幕前面 / 后面 / 中心高 | X114 / X99.5 / Z−4 mm |
| 前壳通窗 | 123×79 mm，按完整外廓留每侧0.5 mm；不假定有效显示区 |
| 厂家安装孔 | 未给出；不使用机壳角螺钉、不借用7/10寸75 mm M4孔 |
| 托架固定 | 4×ISO4762 M3×20+ISO4032 M3捕获螺母，孔轴Y±67、Z−34/26 mm，孔Ø3.4；螺母X98.6..101 |
| 质量 | 200 g工程情景；100～350 g敏感性范围，非厂家参数 |

两件PETG角托以金属外壳作为支撑对象。下部托唇在Z−43接触外壳底面，上部挡唇在Z35.5防止向上脱离，顶面保留0.5 mm装配间隙，左右各留0.5 mm；中段侧面和背面敞开。后面四个支承区与设备之间留0.5 mm，粘贴4×8×0.5 mm柔性垫片后承压。垫片坐标为X99..99.5，Y正侧56..60/负侧−60..−56，Z−38..−30及22..30；这些软垫未作为独立CAD实体，计入装配杂件。

前面板四个小止挡只覆盖外廓最边缘0.5 mm、每处4 mm长，**前缘是否有可受力的金属边必须实物确认，禁止以玻璃或液晶层承受螺钉夹紧力。**未知玻璃范围时不能把本版前止挡当作已获厂家认可的夹持位置。

装配顺序：把M3螺母从托架背面压入六角孔；贴后部软垫；将左右托架从两侧扣合在屏的金属外壳上下角；把屏与托架整体置于拆下的前面板后面，确认止挡与金属边接触，再从前面装4颗标准M3×20，先手拧至托架平面与面板接触，不得用螺钉把未知玻璃边缘强行夹紧。螺杆越过螺母1.6 mm；不裁短螺钉。最后将完整前面板模块装到机壳并连接HDMI与USB供电/数据。

背面接口区采用敞开结构；规格书示意AUDIO/USB5V/HDMI位于背视左侧凹区，接口准确方向和插头尺寸未给出，不绘制虚构接头。需用实物核对弯头、插拔通道和线束弯曲半径。屏幕分辨率、有效区、质量、公差、外壳承载极限均没有5寸单独确证。本托架提供可审查机械接口，未进行跌落、振动、跳跃或玻璃应力认证。

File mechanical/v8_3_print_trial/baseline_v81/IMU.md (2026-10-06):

# HI13R2 安装与坐标

> 打印试装包说明：本文继承历史装配关系；金属工艺、载荷和已通过的检查均只适用于原注明版本。全塑料样件以 [FIT_NOTES.md](../FIT_NOTES.md) 为先，须断电并由独立治具支承，不能照金属工艺强压、强拧或通电。V8.3新版外壳尺寸、打印方向及验证状态以最终打印清单/报告为准。

采用超核官方HI13XX-USB STEP，原始两实体完整导入，不缩放、不镜像。型号HI13R2-USB-000，26×24×12mm（铝壳主体24×24×12），质量按厂商<11g取11g预算。

厂家规格书Rev1.5图9红点给出名义IMU位置：距壳体平面两边各12mm、距底6mm。CAD将该点放在**(X0,Y0,Z85)mm**，与左右髋轴中点的俯视投影重合；安装底面Z79。这是底盘运动学中心，并非修改外形后不规则轮廓的面积重心。官方尺寸公差和实际装配误差仍需标定。

IMU通过2颗M2.5×16和桥下M2.5螺母固定于3mm铝合金桥板，孔心(+10.1,−10.1)、(−10.1,+10.1)，设备孔Ø2.6，桥孔Ø2.7。CNC桥用4颗M3×8直接固定到金属侧框，入口X±10/Y±68/Z47，夹持3mm，名义入牙5mm，侧框底孔深6mm。桥板Z76..79，主机最高约Z67.766，名义垂向间隙8.234mm。

Type-C朝−X。厂家默认RFU轴在现有数值CAD坐标中为Xs→+Y、Ys→−X、Zs→+Z；向量变换 R=[[0,−1,0],[1,0,0],[0,0,1]]。姿态四元数还需明确世界/机体约定，不能仅交换欧拉角。R2为加速度计＋陀螺仪，无磁力计。

设计为刚性安装，不在控制IMU下默认添加软垫。桥上方开窗/通风不代表热验证，线材弯曲半径、振动传递和Jetson风扇气流均需实物验证。

[官方机械资料与来源](source/hi13r2/PROVENANCE.md) · [完整坐标参数](imu_interface.json)

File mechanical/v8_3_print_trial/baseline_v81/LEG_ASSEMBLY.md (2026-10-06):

# V8.1 左右腿模块装配

> 打印试装包说明：本文继承历史装配关系；金属工艺、载荷和已通过的检查均只适用于原注明版本。全塑料样件以 [FIT_NOTES.md](../FIT_NOTES.md) 为先，须断电并由独立治具支承，不能照金属工艺强压、强拧或通电。V8.3新版外壳尺寸、打印方向及验证状态以最终打印清单/报告为准。

本文件适用于一台双腿样机。OB=AC=130、BW=105、OA=BC=45 mm，电机位置和V8腿部主体保持不变。左右腿各自先完成台架装配，再通过4组M4接口安装到机身。电机内部原厂螺钉不拆、不重复计入BOM。

## 拆分与共用

每腿保留9件主结构：髋电机座、髋转子法兰、膝定子杯、OB内框、OB包覆外壳、OA整体叉臂、AC连杆、CW整体叉臂、轮辋。CW上的BC叉不另拆；OA叉耳和OB外壳侧壁均为一体加工，避免靠零散隔柱拼接。

刚体旋转及双向布尔差确认：髋电机座、髋转子法兰、OA、AC、轮辋左右共用同一制造件。其中AC左右转换需要翻面并交换A/C端；不是保持端点标号直接翻面。具体装配变换见 `leg_mirror_equivalence.json`。膝定子杯、OB内/外框及CW保留左右件。主结构从17种制造件降为13种，装配总数仍18件。

关节内原来的12个铜套及12个独立钢隔圈，改成12个一体带肩青铜衬套：内侧6个、外侧6个。每腿硬件97件，两腿194件；其中标准或厂家目录件156件、定制功能小件38件。详见 `leg_hardware_bom.json`，包括腿—机身的8套M4连接，不应在机身清单再次相加。

## 台架装配顺序

1. **来料与成套。** 将右/左OB内外框按配对编号分盘；清除毛刺，检查轴承孔、台阶及M2/M3螺纹，测量轴承实际内径/宽度。先做无胶试装；严禁靠拧螺钉拉正错位销孔。
2. **轴承与衬套预装。** 在每根AC的A/C孔和每根CW的B孔各装1个626ZZ1，共6个。只对轴承外圈施压；安装0.8 mm压盖和3枚SETS-M2-4。检查外圈止口、压盖只接触外圈，内圈转动自由。衬套轻压进OA的A叉、CW的C叉和OB的B支承：Ø8段进入叉耳，Ø8.4肩向中间轴承。内侧总长3.75，外侧总长4.20，不得互换。
3. **轮组预装。** 用每侧3枚ISO4762 M3×8将H6215定子安装于CW。将轮辋定位于转子止口，交叉拧紧6枚ISO4762 M3×8；原图6×M3深5，轮辋孔位夹持4，名义啮合4、孔底余1 mm。装弹性轮胎并检查轮辋径跳、端跳和引线出口。轮辋12枚螺钉在V8.1已补入CAD/BOM。
4. **膝电机与OB内框。** 用每侧6枚SLH-M3-6-SD把OB内框装到膝电机转子外围定子。内框圆孔对转子留空；检查电机转子能独立转动。
5. **OA与AC/CW。** OA穿过内框圆孔，使用6枚ISO4762 M3×16固定到膝转子。此时外侧OB尚未覆盖，六角工具可直达螺钉。将AC的A端嵌进OA叉、C端嵌进CW的C叉，分别穿D6双端内螺纹轴销，再装两端0.2 mm防脱挡片和SETS-M2-4。使用轴销端面对挡片限位，不通过端螺钉给轴承增加预紧。
6. **B点及OB包覆闭合。** 将CW的B轴承对准OB内框B支承，一边保持关节同轴，一边从外侧盖上整个OB包覆外壳，使OA轮毂进入其同轴圆孔/内台阶。先穿B轴销作为对正基准，再均匀锁紧背面的4枚DIN7991 M3×10；它们位于电机圆面之外，可从电机侧安装。装B轴两端挡片/螺钉，检查B点不会因紧固OB而变紧。
7. **角限位最后装。** 从OB外面安装OA的M3装配限位肩销；Ø7头不能预先穿过4.6 mm弧槽。它只防装配越位，不能承受带电撞停或跳跃落地冲击。建立编码器零位和软件限位后，软件范围应在机械端点内留余量。
8. **髋电机半模块。** 用6枚DIN7991 M3×6把髋座装在髋定子；把3枚标准DIN6325 Ø4m6×10装入髋转子法兰，控制法兰插入7.00±0.05 mm（向电机伸出名义3 mm，随实际销长变化），再用6枚ISO4762 M3×8装到髋转子。实际电机定位孔须能徒手对合，不以螺钉拉入；法兰销孔需按实机确认孔位置。
9. **髋/膝嵌套。** 用4枚SLH-M3-6-SD先将定子杯装到膝电机后端（杯口尚未嵌套，可接近螺钉）。让杯口套入髋转子法兰的Ø43导向段，四处径向孔对准后装4枚SLH-M3-8-SD，分次交叉锁紧。线缆先按运动弯曲余量引向机身，避免夹在杯口。
10. **单腿台架验收。** 断电手动缓慢通过计划工作行程，检查A/B/C无卡滞、连杆不擦叉耳、OA不擦包覆壳、轮组转动自由。复查每个螺钉深度、防松记录、衬套方向和线缆。左右腿分别通过后才总装。

## 模块总装与维护

先组装机身金属骨架并保留内部工具空间；分别把左右腿髋座装到侧框，每侧4枚DIN7991 M4×12、4片ISO7089 M4平垫、4枚ISO4032 M4螺母。螺母与垫圈位于机体内侧，需在电器托盘和外壳封闭前完成紧固。按整机指南再装电器仓、前脸和外壳；最后接插电机电源/CAN并做方向检查。

拆卸按相反次序。更换A/C轴承需要拆相应关节轴，再取下压盖；不要从滚珠传力敲出轴承。拆B轴承或OA时先移除角限位销，再拆OB外壳。螺钉防松、表面润滑和最终拧紧力矩需经过该连接的试拧/验证确定；NBK目录给出的上限不能直接用作薄铝壁、M2小螺纹或铜套的装配力矩。

工具：2 mm及2.5 mm内六角、TX4、AF7薄壁套筒、≤0.8 mm一字刀、低量程扭矩工具、轴承外圈压套、支撑铜套端面的压装夹具、通止规/千分尺。压装工具不得把安装力施加在0.2 mm径向宽度的铜套窄肩上。

## 已核对的采购来源

- [NBK SLH-SD图纸](https://www.nbk1560.com/images/en-US/product/lowsmallheadscrew/SLH-SD/SLH-SD_1.pdf)：M3头Ø4.5×2，8.8级SWCH45K发黑，小头面压需单独检查。
- [NBK SETS](https://www.nbk1560.com/en-US/products/specialscrew/nedzicom/spacesaving/SETS/)：M2×4、头Ø4×0.5、TX4，SUSXM7。
- [NSK626ZZ1](https://www.nsk.com/jp-ja/engineering/products/bearings/ball-bearings/deep-groove-ball-bearings/extra-small-ball-bearings-and-miniature-ball-bearings-metric-series/6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)：6×19×6。轴承额定载荷不构成整条腿的跳跃承载证明。
- [Bossard BN20](https://www.bossard.com/us-en/eshop/screws-and-bolts-with-internal-drive/hex-socket-flat-countersunk-head-screws-fully-threaded/p/20/)：DIN7991目录系列，换成ISO10642必须重新核对头部包络。
- [Norelem DIN6325图纸](https://www.norelem.mx/doc/mx/es/did.97191/03320_Datasheet_2785_Pasadores_cil_ndricos_DIN_6325--es.pdf)：可采购Ø4×10淬硬磨削销，取代非优选的9 mm定制长度。

电机孔位依据用户提供的J4310 V1.1及H6215原厂图，摘录图和文本保存在 `source/hardware/`。螺纹在CAD中按孔/省略啮合段表示；不得以CAD中可见的短杆段误算采购长度。

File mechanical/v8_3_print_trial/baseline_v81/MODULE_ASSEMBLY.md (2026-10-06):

# V8.1 模块预装与总装顺序

> 打印试装包说明：本文继承历史装配关系；金属工艺、载荷和已通过的检查均只适用于原注明版本。全塑料样件以 [FIT_NOTES.md](../FIT_NOTES.md) 为先，须断电并由独立治具支承，不能照金属工艺强压、强拧或通电。V8.3新版外壳尺寸、打印方向及验证状态以最终打印清单/报告为准。

适用一台样机。模块分为 M01 左腿、M02 右腿、M03 金属机架、M04 电器仓、M05 屏幕相机前脸、M06 外壳。左右腿以整腿为预装单元；电器仓分为电池与托盘、Jetson 托盘、IMU 桥三个可维修的子模块。采用新电池图纸后，三者均可先在机外预装，再按电池模块 → Jetson → IMU 的顺序接入完整双腿机架。外壳不承担腿部主载荷。

本版不要求拆开腿连杆才能装机，但**四颗髋座螺钉不能在同一个腿姿态下全部使用直内六角工具锁紧**。详见下方两姿态操作。坐标约定：+X 为机器人前方，+Z 为上方，±Y 为左右腿外侧；下表 X/Z 对两侧腿相同。

## 机外预装

| 模块 | 机外完成内容 | 总装前检查 |
|---|---|---|
| M01 / M02 左右腿 | 髋座及髋电机、两件髋膝法兰、膝电机、OB 内座、OA、AC/CW 及轴承、OB 外罩、轮毂电机与轮圈 | 区分内/外带肩铜套长度；轴承压装力只作用被配合套圈；检查关节顺滑、紧固件与限位方向；四颗髋座 M4 已预放 |
| M03 金属机架 | 左右髋框、前后通用横框、底板，保持上方与前后开放 | 两侧安装面、4×Ø4.4 孔组及框架方正；电器仓保持空置，供整腿内侧工具操作 |
| M04-A 电池模块 | 按新图的含磁底 85.6X×44.5Y×61.6Z 包络放入一体托盘；离机穿好两条束带并固定电池，DC 所在侧面朝上 | 选用用户确认的 E626S；磁吸仅辅助定位。束带宽≤10 mm、托底单层厚≤1 mm，搭接置于上方并避开实际 DC 插头；400 g 仍为含附件预算 |
| M04-B Jetson 托盘 | 原装开发套件、托盘、左右一体托夹及托盘下方螺母 | 托夹固定原装底座而非夹 PCB；四个总装螺钉通道保持开放 |
| M04-C IMU 桥 | HI13R2 与金属桥 | 标记传感器方向；保持名义原点 (0,0,85)，不随意加入软隔振垫 |
| M05 前脸 | 5 寸屏、两件屏托、四片软垫、D435 与一体后座、完整前面板 | 屏幕前挡只能接触已确认的金属边；相机后座按实物 25.05 / 26.05 mm 深度二选一 |
| M06 外壳 | 前壳、后盖、通用肩罩两件分别去支撑、清孔、试合 | 捕获螺母孔试装；不要先把整个机身包住再试图锁腿 |

腿部内部按连接依赖顺序预装：髋座和髋电机 → 髋膝两法兰与膝电机 → 膝定子上的 OB 内座 → 通过内座中心开口安装 OA → 轴承/带肩铜套与 AC/CW 联接 → 合上 OB 外罩 → 安装 OA 角度限位销 → 轮组。可在合外罩前完成关节预装，避免先封罩后寻找内侧轴端螺钉。紧固件数量、规格及定制件以本版 BOM 为准。

**在髋座仍裸露时，先把每侧四颗 DIN7991 M4×12 沉头螺钉放入髋座沉孔。** 用可移除的临时保持方法防掉；M4 垫片和螺母不随腿穿过机架，在整腿就位后从机内安装。不能把 Ø3.2 工具杆可通过误当作 Ø8 螺钉头也可穿过已装好的连杆。

## 左右整腿接入机架

1. 固定 M03，分别在夹具上支撑整腿及轮组，电机断电。髋轮距先设为 180 mm、Beta=0°，保持腿平面及四颗预装 M4 螺杆对准机架孔组。
2. 右腿沿 −Y、左腿沿 +Y 靠近机架。髋电机穿过中央窗口，四颗螺杆穿 Ø4.4 孔，髋座安装面贴合机架。禁止用螺母强拉歪斜的孔位。
3. 从机内装四片 M4 平垫和四颗普通 M4 螺母，先轻贴合，继续由夹具承托整腿。此时电池模块、Jetson、IMU 及外壳均未安装，电器仓供内侧套筒和延长杆操作。
4. 按下表切换两个已检查姿态，使用直工具锁紧对应螺钉。**移出工具后才可调整姿态**；支撑件继续承托机体和轮组，不依靠未锁紧连接承受整机重量。
5. 所有螺钉完成锁紧后复查安装面贴合、螺母标记及手动活动。两侧均完成后，再安装电器仓；无需改变保存的机器人名义姿态或控制参数。

| 髋座 M4 位置（X/Z，mm） | 工具可达装配姿态：髋轮距 / Beta |
|---|---|
| 后上 −30 / +30 | 110 mm / 0° |
| 后下 −30 / −30 | 165 mm / 0° |
| 前上 +30 / +30 | 165 mm / 0° |
| 前下 +30 / −30 | 165 mm / 0° |

外侧使用 AF2.5 直内六角，受检工具包络为 **Ø3.2，Y77.85～230 mm**（另一腿镜像）。内侧使用 **AF7、外径不大于 10.5 mm 的薄壁套筒**，头部深度通道 Y30～71.15 mm，配 Ø6 延长杆通道 Y−20～30 mm。已有 Ø11 让位使套筒名义径向余量为 0.25 mm。采购工具应核对实际外径；“AF7”本身不保证所有品牌外径相同。工具检查不包含手掌、手柄摆动及扭矩能力；不要用球头偏斜来替代本表的直工具操作。最终扭矩依实际螺钉、表面处理和结构载荷确定，本文件不虚构通用扭矩。

100～215 mm、每 5 mm 一档的 24 个姿态没有发现“四条工具线同时无遮挡”的姿态。这是装配顺序约束，不是必须拆腿的理由，也不能写成默认 180 mm 下四颗都可锁。逐颗可达姿态、遮挡对象和几何检查原始结果见 `module_access_review.json`。

## 电器仓与外壳总装

1. 两腿接合完成后，将已预装的 **完整 M04-A 电池＋托盘＋两条束带模块** 从上方向下放入。此时髋轮距恢复 180 mm、Beta=0°；上方主机盘、IMU、前脸及外壳尚未安装。四个耳座落到 X±70 / Y±20、Z−39 的原安装基准，再用四颗 M3×8 从上方锁紧。对完整双腿机架 241 个对象的连续 100 mm 竖直扫掠，以及四条 Ø3 工具通道均已通过，见 `battery_local_review.json`。这个证明包含托底单层 1 mm 束带占位，未包含未选定的插头、扣头和线束。
2. 从上方放入完整 M04-B，落到托盘支承面，再用四颗 M3×8 从上方锁紧。四个螺钉中心为 X−74 / +38、Y±48 mm。新托夹让位已检查 Ø3 直工具杆通道；四颗机外托夹螺母不必在机内重新散装。
3. 装 M04-C，用四颗 M3×8 固定桥脚。IMU 敏感轴方向与中心基准按 `IMU.md` 核对，线缆留可拆接口。
4. 装前壳，通过尚未安装前脸的大开口拧紧四颗 M3×12。装入前脸四枚捕获螺母；后盖保持开放以便接线和手动检查。
5. 用台面支撑预装好的 M05，接入相机、屏幕线缆并整理应力释放，再把整个前脸装到机壳，用四颗 M3×12 固定。屏幕使用标准 M3×20，相机采用一体 6 mm 后座配标准 M3×8，不再裁短螺钉或堆散垫片。
6. 检查内部线束与风扇、腿运动空间及前脸无挤压后，装后盖四颗 M3×12、两侧肩罩共四颗 M3×20。首次检查再拆回机外完成整改，不用装饰壳承受临时工装载荷。

新电池本体尺寸 85.6×61.6×42 mm，含磁底厚 44.5 mm。按图放置后顶部为 Z17.8，距上方电器盘底 Z30 为 12.2 mm；预留 11 mm 连接器检查区后仅余 1.2 mm。必须先实测紧凑弯头、线径与弯曲半径，并保证束带搭接避开 DC 口；这不是实际插头已获验证。托底至底板凹台间隙 1.8 mm，托底带材不得折返或叠层。详见 `BATTERY.md`、`BATTERY_SOURCE_REVIEW.md`。

本版机身连接细节和逐件标准件数量见 `BODY_ASSEMBLY.md`。Jetson 四条工具线及一体托夹连续实体检查见 `body_detail_review.json`。

## 范围与维修

审查使用实际刚体 CAD、指定工具包络和离散整腿轴向靠近位置；不等于完整的人手装配仿真、连续运动证明、跳跃强度或工艺公差鉴定。厂家模型中省略的线缆、接头和印制标识仍需实物核对。

电池和托盘支持作为完整模块向上取出：先移开上方电器模块及装配路径中的机壳/前脸，断开电源线，拆四颗托盘螺钉，再沿已验证的竖直路径反向操作；不必为电池托拆腿。不得把这条开放状态的路线理解为封壳后可直接抽出电池。Jetson 在新电池、V8.1 托夹及全部 12 件随托紧固件下的维修路径已另行通过：先断电并拆开模块线缆，移走两侧肩罩、后盖、后横框及其紧固件和四颗托盘螺钉，共拆 16 颗螺钉；托盘保持完整，先上抬 4 mm，再向后移出 180 mm。两段固定朝向的连续保守包络均无相交，抬升后距髋电机的名义竖向余量 1.5 mm；直接在原高度后抽会碰到髋电机。后横框自身仅检查了 6 个离散退出位置，未证明全部连续路径；实际线缆、人手及制造误差仍需实物试装。原始范围和结果见 `maintenance_access_review.json`。

整腿更换先移除电池模块及上部电器、前脸和外壳，将机身恢复到本页审查的空金属框架状态，承托机体和待拆腿，再按 110 / 165 mm 两姿态反向操作四组 M4。此方案支持整腿取下，不表示装满电器、封着外壳仍能直接拆腿。

新托盘还作为额外障碍物参与了四条内侧 AF7 工具通道和整腿轴向接合的独立检查，均无相交。这一附加检查不改变推荐顺序：仍先锁好两腿，再装完整电池模块，以保留最大的实际操作空间。

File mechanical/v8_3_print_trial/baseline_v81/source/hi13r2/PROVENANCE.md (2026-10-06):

# HI13R2 官方资料与装配基准

> 打印试装包说明：本文继承历史装配关系；金属工艺、载荷和已通过的检查均只适用于原注明版本。全塑料样件以 [FIT_NOTES.md](../../../FIT_NOTES.md) 为先，须断电并由独立治具支承，不能照金属工艺强压、强拧或通电。V8.3新版外壳尺寸、打印方向及验证状态以最终打印清单/报告为准。

获取日期：2026-09-22。型号选用 **HI13R2-USB-000**。以下来自厂家发布的 HI13 共用外壳资料；R2 内部配置为加速度计和陀螺仪，无磁力计、无气压计。

## 来源

- [产品页面](https://www.hipnuc.com/hi13.html)：26×24×12 mm、铝合金外壳、重量小于11 g、USB Type-C。
- [官方资源索引](https://download.hipnuc.com/products/)：从其中 HI13 的规格书、3D 模型链接取得文件。
- [官方规格书](https://download.hipnuc.com/datasheets/hi13_datasheet_cn.pdf)：Rev 1.5，2026-03-14；原文件 `hi13_datasheet_cn.pdf`。
- [官方 STEP 压缩包](https://download.hipnuc.com/3d/hi13_3d.zip)：内含 `HI13XX-USB.STEP`，压缩包内文件时间2026-03-16；原始模型留在完整工程；本打印包只附文档和尺寸页，不包含这项设备的 STEP/ZIP。

第17、18、19页已分别渲染为 `datasheet-17.png`、`datasheet-18.png`、`datasheet-19.png`，用于机械尺寸、安装要求和坐标轴的目视核对。文本抽取另存 `hi13_datasheet_cn.txt`。

## 机械与原点

第17页图9给出壳体24×24×12 mm，接口突出2 mm，总包络26×24×12 mm。两处对角贯穿安装孔为 **Ø2.6 mm**，X/Y方向中心距均为 **20.2 mm**；安装螺钉采用 M2.5。接口端面的 **2×M2、15 mm间距** 是连接器锁紧板螺孔，不能与竖直安装孔混用。

图9以红点标注 IMU 位置，D4=12 mm、E3=12 mm、A3=6 mm，分别从壳体两边与安装底面定位。三个参数表格范围均为名义值±0.2 mm。该点是厂家公布的模块名义参考点，并非对每台设备芯片实际敏感中心的独立标定结果。

本装配将该名义点放在机器人 **(X,Y,Z)=(0,0,85) mm**，安装底面 **Z=79 mm**，上表面 **Z=91 mm**；俯视参考点落在机器人坐标原点。安装孔世界坐标为 **(10.1,−10.1)**、**(−10.1,10.1)**。最大头部高度会达到Z91.9：Ø4.5×2.5 mm的M2.5圆柱头落在Z89.4的螺钉支承面上。

建议与3 mm厚刚性金属桥搭配：桥Z76..79、Ø2.7通孔、M2.5×16螺钉和桥下约2 mm厚螺母，螺钉末端Z73.4。紧固件的真实头部、螺母和螺纹长度仍应按所购物料校核。不采用未标定的软垫悬置。

## STEP 到机器人坐标变换

原 STEP 含两个有效实体，主要为外壳和盖板；未凭空增加内部 PCB、芯片或USB插头。STEP 的壳顶指向原始 **−Z**，接口朝 **+Y**；这一点由前部螺孔翻转后距底4.95 mm吻合图纸A2=5，以及顶部安装槽支承面距底10.4 mm吻合A1=10.4交叉核对。

原始图示 IMU 点：`(-40.00155697274189, 1.47316173360338, 0)`。

安装变换（单位mm）：

```text
X_robot = -(Y_STEP - 1.47316173360338)
Y_robot = -(X_STEP + 40.00155697274189)
Z_robot = 85 - Z_STEP
```

这是行列式为+1的刚性旋转和平移，没有镜像。接口朝机器人 **−X**，便于将线束引向后部。

第19页图10定义默认传感器 **RFU** 轴：Y朝接口、Z朝上。安装后，传感器Xs对应CAD +Y，Ys对应CAD −X，Zs对应CAD +Z。将原始加速度、角速度转换到CAD数值坐标，应采用：

```text
v_CAD = [[0, -1, 0],
         [1,  0, 0],
         [0,  0, 1]] * v_sensor
```

这里明确使用CAD数值轴，不依赖旧模型左右侧命名。姿态四元数/欧拉角需按固件的参考坐标、输出约定做完整外参转换，不能直接置换欧拉角。当前没有修改控制器或设备配置。

## 质量和边界

- 重量预算使用 **11 g**，对应厂商“小于11 g”的保守上界，不按空心外壳体积代替整机IMU质量。
- 规格书表11最大功耗300 mW，USB供电范围4.5..5.5 V。
- `cable_clearance()` 只提供20×12×9 mm设计预留区，**不是**厂家USB线插头模型；实际选线后应复核插头、弯曲半径和应力释放。
- 安装应平整、刚性固定，远离集中热源，避免线束持续拉扯；跳跃与振动工况需在整机上实测验证。
- `model_validation.json` 检查真实STEP的有效性、2个实体、26×24×12 mm包络、底面高度、原点转换，以及两个孔轴Ø2.5探针无实体重叠/螺钉支承环存在材料。

可复现代码：`tools/cad_v7_imu.py`；装配接口参数：`interfaces.json`。安装BRep缓存 `hi13r2_placed_z79.brep` 来自原始实体刚性移动，原始STEP始终保留。

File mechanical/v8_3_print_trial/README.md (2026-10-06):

# V8.3 全定制件打印试装包

用途：先用PETG验证零件分块、孔位、嵌套关系和装配顺序，之后再加工原金属承力件。电机和电子模块使用您已有的实物；螺钉、螺母、标准垫片、轴承、定位销使用真实标准件。

本包包含 **38 种定制零件、共 77 件**的单件STL，包含原24种金属加工件。另附一个可选孔径校准板，不计入77件。每个文件只放一种零件，数量按文件名`_xNN`及清单；不要把所有STL导入同一打印盘直接开打。

## 快速入口

- [打印清单](打印清单.md)：编号、数量、模块、尺寸和建议层高。
- [原设计材料与工艺分类](制造工艺分类.md)：区分后续金属加工件与原本的打印件。
- `STL/`：左右腿、双腿通用件、机架、电器仓、前脸、外壳等分组。
- [标准件采购表](采购BOM.xlsx)及[采购CSV](采购清单.csv)：已有电机和电子模块不重复采购。标准件按完整单机需求列出，填已有库存后扣减；轮胎/耗材和待选型件另行核实。
- [精细零件与试装注意事项](FIT_NOTES.md)：0.20mm挡片、小销、衬套和螺纹的限制。
- [模块装配顺序](MODULE_ASSEMBLY.md)：优先机外预装，再整体组合。
- `STEP_reference/`：同一版名义实体，用于核对尺寸；不是另一个需要再打印的零件集合。
- [可选孔径校准板孔位图](00_optional_calibration/孔位图.svg)：4/6/8/19mm四列，直径附加0/.15/.30mm三排。

## 外观变化

白色圆角包边、黑色前脸、低矮胶囊形相机边框、橙色浅槽涂装区。主体棱边进一步增大圆角，两只加大的小机械手与前主壳一体，不增加运动机构。最终圆角和手部尺寸见[外观修改记录](DESIGN_CHANGES.md)，打印包络见打印清单。腿部、机架、内部设备和已布置的开关/USB/充电接口位置沿用V8.2。

STL不含颜色，白/黑/橙效果通过不同零件颜色和局部涂装实现；浅槽不是灯具。固定小手不能用于提起整机或支承机体。

## 打印与试装

1. 打印机沿用220×220×250mm、0.4mm喷嘴、PETG。导入单位为mm、比例100%，STL已置于打印床上；支撑、温度和速度采用您机器验证过的配置。
2. 先打印校准板、一个关节的小件及一对髋膝法兰，核对实物轴承/销/电机。不要用整件缩放去消除局部配合误差。
3. 再打印单腿、机架与电子支架，最后打印机壳和另一条腿。必要的扩孔、轻磨和攻牙逐项记录，避免将打印误差当作设计错误。
   可准备游标卡尺、小锉、手钻、与对应底孔匹配的M2/M3丝锥及M3板牙；已有工具不需重复购买。螺纹底孔不可当通孔任意扩钻。
4. LC05为实际0.20mm薄挡片；同厚片材替代属于可选措施，不能加厚或用普通M2平垫改变轴向堆叠。
5. 全塑料样机仅用于断电、由桌面/治具独立支承的手动试装；不能让打印腿承受整机重量，也不进行通电行走或跳跃。FDM样件不能验证原金属件的微米级配合和强度。

## 检查范围

所有单件STL已检查封闭、非流形、自交、法向、落床及打印包络；只做刚体旋转平移，未放缩、扩孔或更改定制件名义尺寸。切片器支撑和薄层成形仍须预览确认；没有提供未经实机验证的G-code。

STL导出按毫米约定，参见[FreeCAD官方导出说明](https://github.com/FreeCAD/FreeCAD-documentation/blob/main/wiki/Export_to_STL_or_OBJ.md)；FDM配合需实测工艺，参见[Prusa原厂设计指南](https://help.prusa3d.com/article/modeling-with-3d-printing-in-mind_164135)。

源CAD SHA256：`6c412e7decafa3248ac72778895a7d07f83699d7fd820d27fb9a8fe7ba220aa5`。`print_manifest.json`保存逐件源文件和STL哈希、摆放变换、打印参数及检查结果。V8.2原文件保持不变。

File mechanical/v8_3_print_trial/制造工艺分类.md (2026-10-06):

# 原设计材料与制造工艺

本次38类定制件全部提供PETG形状试装STL。下表保留原设计材料，供试装完成后安排金属加工；不代表强度或跳跃性能已经验证。原金属件不能凭塑料样件装得上就改为长期打印承力件。

|编号|零件|数量|原设计材料|原设计工艺|
|---|---|---:|---|---|
|P01|机架底板|1|6061-T6铝合金|CNC铣削/车铣|
|P02|右承力侧框|1|6061-T6铝合金|CNC铣削/车铣|
|P03|左承力侧框|1|6061-T6铝合金|CNC铣削/车铣|
|P04|前后通用横框|2|6061-T6铝合金|CNC铣削/车铣|
|P05|前主壳|1|PETG|FDM 3D打印|
|P06|后检修壳|1|PETG|FDM 3D打印|
|P07|屏幕相机前脸板|1|PETG|FDM 3D打印|
|P08|左右通用肩罩|2|PETG|FDM 3D打印|
|P09|电池托|1|PETG|FDM 3D打印|
|P10|电器托盘|1|PETG|FDM 3D打印|
|P11|Jetson右夹座|1|PETG|FDM 3D打印|
|P12|Jetson左夹座|1|PETG|FDM 3D打印|
|P13|D435一体后座|1|PETG|FDM 3D打印|
|P14|IMU刚性安装桥|1|6061-T6铝合金|CNC铣削/车铣|
|P15|屏幕右托夹|1|PETG|FDM 3D打印|
|P16|屏幕左托夹|1|PETG|FDM 3D打印|
|P17|左右通用髋定子座|2|6061-T6铝合金|CNC铣削/车铣|
|P18|左右通用髋转子法兰|2|6061-T6铝合金|CNC铣削/车铣|
|P19|右膝定子套杯|1|6061-T6铝合金|CNC铣削/车铣|
|P20|左膝定子套杯|1|6061-T6铝合金|CNC铣削/车铣|
|P21|右OB内框|1|6061-T6铝合金|CNC铣削/车铣|
|P22|左OB内框|1|6061-T6铝合金|CNC铣削/车铣|
|P23|右OB外包主臂|1|6061-T6铝合金|CNC铣削/车铣|
|P24|左OB外包主臂|1|6061-T6铝合金|CNC铣削/车铣|
|P25|左右通用OA曲柄|2|6061-T6铝合金|CNC铣削/车铣|
|P26|左右通用AC轴承连杆|2|6061-T6铝合金|CNC铣削/车铣|
|P27|右CW下臂|1|6061-T6铝合金|CNC铣削/车铣|
|P28|左CW下臂|1|6061-T6铝合金|CNC铣削/车铣|
|P29|通用轮辋|2|6061-T6铝合金|CNC铣削/车铣|
|LC01|轴承外圈压盖|6|不锈钢板|精密薄板切割/整平|
|LC02|双端内螺纹关节轴销|6|40Cr调质后精磨；具体硬度按试验定|CNC车削/精磨/二次加工|
|LC03|内侧一体带肩衬套|6|轴承青铜CuSn12|CNC车削/精磨/二次加工|
|LC04|外侧一体带肩衬套|6|轴承青铜CuSn12|CNC车削/精磨/二次加工|
|LC05|轴销薄防脱挡片|12|钢精密垫片料|精密薄板切割/整平|
|LC06|OA装配限位肩销|2|钢；强度待验证|CNC车削/精磨/二次加工|
|P30|配电通信一体安装架|1|PETG|FDM 3D打印|
|P31|背部USB扩展坞压托|1|PETG|FDM 3D打印|
|P32|后充电口可换安装板|1|PETG|FDM 3D打印|

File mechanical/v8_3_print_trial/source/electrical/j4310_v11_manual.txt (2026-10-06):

DAMIAO 达妙科技
DM-J4310-2EC V1.1
减速电机

使用说明书 V1.2 2026-09-08

                 © 2019-2026 深圳市达妙科技有限公司 版权所有

                          深圳市达妙科技有限公司 DM-J4310-2EC V1.1 使用说明书 V1.2

目录
 历史版本........................................................................................................................................... 4
 免责声明 .......................................................................................................................................... 5
 注意事项........................................................................................................................................... 5
 电机特色........................................................................................................................................... 5
 特征参数........................................................................................................................................... 6
 ◈ 工作电压...................................................................................................................................... 7
 ◈ 最大相电流. ................................................................................................................................. 7
 ◈ 最高转速...................................................................................................................................... 7
 ◈ 扭矩系数...................................................................................................................................... 7
 效率曲线........................................................................................................................................... 8
 物品清单........................................................................................................................................... 8
 接口及线序说明................................................................................................................................. 8
 电机尺寸及安装................................................................................................................................. 9
 指示灯状态........................................................................................................................................ 9
 工作模式......................................................................................................................................... 10
 ◈ MIT 模式.................................................................................................................................... 10
 ◈ 位置速度模式............................................................................................................................. 10
 ◈ 速度模式.................................................................................................................................... 10
 ◈ 力位混控模式............................................................................................................................. 11
 ◈ 模式修改.................................................................................................................................... 11
 CAN 通信........................................................................................................................................ 11
 ◈ 修改波特率. ............................................................................................................................... 11
 ◈ 反馈帧....................................................................................................................................... 11
 ◈ MIT 模式下的控制帧................................................................................................................... 13
 ◈ 位置速度模式下的控制帧. ........................................................................................................... 14
 ◈ 速度模式下的控制帧................................................................................................................... 14
 ◈ 力位混控模式下的控制帧. ........................................................................................................... 14
 ◈ 使能. ......................................................................................................................................... 15
 ◈ 失能. ......................................................................................................................................... 15
 ◈ 保存位置零点............................................................................................................................. 15
 ◈ 清除错误.................................................................................................................................... 15
 ◈ 读取参数.................................................................................................................................... 15
 ◈ 写入参数.................................................................................................................................... 16
 ◈ 存储参数.................................................................................................................................... 16
 ◈ 模式切换.................................................................................................................................... 16

                                                            第 2 页 共 45 页

                          深圳市达妙科技有限公司 DM-J4310-2EC V1.1 使用说明书 V1.2

目录
 ◈ CAN 波特率修改......................................................................................................................... 17
 ◈ 寄存器列表及范围. ..................................................................................................................... 17
 电机调试流程. ................................................................................................................................. 19
 ◈ 连接设备.................................................................................................................................... 19
 ◈ 电机侧编码器校准. ..................................................................................................................... 20
 ◈ 参数标定.................................................................................................................................... 22
 ◈ 输出轴编码器校准. ..................................................................................................................... 23
 ◈ 串口读写参数............................................................................................................................. 25
 ◈ 调试. ......................................................................................................................................... 27
 固件版本查看与升级........................................................................................................................ 43
 ◈ 版本查看.................................................................................................................................... 43
 ◈ 串口固件升级............................................................................................................................. 43
 ◈ CAN 固件升级............................................................................................................................ 44

                                                            第 3 页 共 45 页

             深圳市达妙科技有限公司 DM-J4310-2EC V1.1 使用说明书 V1.2

历史版本

   日期        版本                            变更内容

2023-11-16   V1.0                          初版创建
                              48V 版本电机“空载最大转速”参数补充
2026-08-01   V1.1
                    文档内容增补（“电机调试流程”、“固件版本查看与升级”等章节）
2026-09-08   V1.2              过流防护系数更正为“不超过 0.98”

                            第 4 页 共 45 页

            深圳市达妙科技有限公司 DM-J4310-2EC V1.1 使用说明书 V1.2

免责声明
  感谢您购买达妙科技 DAMIAO DM-J4310-2EC V1.1 减速电机（以下简称“电机”）。在使用本产品之前，
请仔细阅读并遵循本文及达妙科技提供的所有安全指引，否则可能会给您和周围的人带来伤害，损坏本产品或
其他周围物品。一旦使用本产品，即视为您已经仔细阅读本文档，理解、认可和接受本文档及本产品所有相关
文档的全部条款和内容。您承诺仅出于正当目的使用本产品。您承诺对使用本产品以及可能带来的后果负全部
责任。达妙科技对于直接或间接使用本产品而造成的损坏、伤害以及任何法律责任不予负责。
  DAMIAO 是深圳市达妙科技有限公司的商标。本文出现的产品名称、品牌等，均为其所属公司的商标。本
产品及手册为深圳市达妙科技有限公司版权所有。未经许可，不得以任何形式复制翻印。本文档及本产品所有
相关的文档最终解释权归深圳市达妙科技有限公司所有。如有更新，恕不另行通知。

注意事项
  1. 请严格按照规定的工作环境及绕组最大允许温度范围使用电机，否则会对产品造成永久性不可逆转的损坏。
  2. 避免杂物进入转子内部，否则会导致转子运行异常。
  3. 使用前请检查各零部件是否完好。如有部件缺失、老化、损坏等，请停止使用。
  4. 确保正确接线，电机安装正确、稳固。
  5. 使用时勿触摸电子转子部分，避免意外发生。电机大扭矩输出时，会出现发热的情况，请注意避免烫伤。
  6. 用户请勿私自拆卸电机，否则会影响电机的控制精度，甚至会导致电机运行异常。

电机特色
  1. 双编码器，输出轴单圈绝对位置，不惧掉电输出轴绝对位置丢失。
  2. 电机和驱动器一体化设计，结构紧凑，集成度高。
  3. 支持上位机可视化调试，支持固件升级。
  4. 可通过 CAN 总线反馈电机速度、位置、转矩、电机温度等信息。
  5. 具有双温度保护功能。
  6. 位置模式下支持梯形加减速。

                           第 5 页 共 45 页

         深圳市达妙科技有限公司 DM-J4310-2EC V1.1 使用说明书 V1.2

特征参数
 请根据以下参数合理使用电机。

            型号          DM-J4310-2EC V1.1     DM-J4310-2EC V1.1（48V）
            额定电压        24V                   48V
            额定相电流       2.5A
            峰值相电流       7.5A
电机参数
            额定扭矩        3NM
            峰值扭矩        7NM
            额定转速        120rpm
            空载最大转速      200rpm                400rpm
            减速比         10: 1
            极对数         14
电机特征值
            相电感         340uH
            相电阻         0.65Ω
            槽数          24
            外径          57mm
结构与重量
            高度          46mm
            电机重量        约 300g
            编码器位数       14 位
编码器         编码器个数       2
            编码器类型       磁编（单圈）
            控制接口        CAN@1Mbps
通讯
            调参接口        UART@921600bps
                        MIT 模式
                        位置速度模式
            控制模式
                        速度模式
                        力位混控模式
                        驱动过温防护，防护温度：120℃，过温电机将退出“使能
                        模式”。
                        电机过温防护，根据使用需求设定，建议不超过 100℃，过
                        温电机将退出“使能模式”。
                        电机过压防护，根据使用需          电机过压防护，根据使用需
控制与保护                   求设定，建议不超过 32V，        求设定，建议不超过 60V，
                        过压将退出“使能模式”。          过压将退出“使能模式”。
            保护          通讯丢失防护，设定周期内没有收到 CAN 指令将自动退出“使
                        能模式”。
                        电机过流防护，根据使用需求设定，建议不超过 0.98，过流
                        将退出“使能模式”。
                        电机欠压防护，若电源电压          电机欠压防护，若电源电压
                        低 于 设 定 值， 则 退 出“ 使   低 于 设 定 值， 则 退 出“ 使
                        能模式”，电源电压不低于          能模式”，电源电压不低于
                        15V。                  20V。

                        第 6 页 共 45 页

                深圳市达妙科技有限公司 DM-J4310-2EC V1.1 使用说明书 V1.2

◈ 工作电压
  24V 版本电机驱动工作电压范围为 24V-28V，最低工作电压为 20V，最高工作电压为 28V；48V 版本电机
驱动工作电压为 24V-48V，最低工作电压为 20V，最高工作电压为 58V，超过 36V 建议减少热插拔。

◈ 最大相电流
  可以通过上电时串口打印信息查询相应驱动器的最大相电流，示例如下：

  可以通过调试助手进行设置运行的最大相电流百分比来进行限定，默认为 0.8，即能采样的最大电流的
80%，建议此值不要超过 98%。

◈ 最高转速
  最高转速由多种因素限制，包括电源电压 (VBUS) 和磁链值 (ψf)，以及减速比（GR），通常可由下式计算
出一个上限，工作中限定到 2000rpm（转子侧）。

  式中：
  VBUS ：电源电压；

  Npp ：电机极对数；

  GR：电机减速比 ;

  ψf：转子磁链。

◈ 扭矩系数
  电机的扭矩系数在额定范围内可视为常数，加上减速箱之后可用如下公式进行计算：

  式中，

  Npp：极对数；
  ψf：转子磁链 ;

  GR：电机减速比 ;

  GREF：减速箱力矩传递系数。

                               第 7 页 共 45 页

               深圳市达妙科技有限公司 DM-J4310-2EC V1.1 使用说明书 V1.2

效率曲线
  定速 120rpm，室温 25℃下，测得的性能曲线图：

物品清单
  1. 电机（含驱动）×1
  2. 电源（含 CAN 通信端子）连接线：XT30(2+2)-F 插头连接线 ×1
  3. 调试串口信号线：GH1.25 连接线 -3pin ×1

接口及线序说明

 具体名称 - 序号             接口标注                            说明

   电源接口 -1
                                         1. 通过 XT30(2+2)-F 插头的电源连接线连接电
（含 CAN 通信端子）
                                         源，额定电压为 24V，为电机供电。
                                         2. 通过 CAN 通信端子连接外部控制设备，可接
                                         收 CAN 控制命令，反馈电机状态信息。
                                         3. 电机包含两个电源接口，任一接口可单独连
   电源接口 -2
                                         接使用，也可多机串联使用，方便走线。
（含 CAN 通信端子）

                                         通过 GH1.25 连接线 -3pin，使用 USB 转 CAN
                                         调试工具（或使用通用 USB 转串口模块）连接
  调试串口 -3
                                         到 PC，通过达妙科技调试助手对电机进行参数
                                         设置，以及固件升级等。

                              第 8 页 共 45 页

         深圳市达妙科技有限公司 DM-J4310-2EC V1.1 使用说明书 V1.2

电机尺寸及安装
 请参考安装孔尺寸将电机和驱动器安装到对应设备上。

指示灯状态

                  绿灯常亮         ERR 位为 1，表示使能模式，正常工作状态。
正常状态
                  红灯常亮         ERR 位为 0，表示失能模式（上电后默认状态）。

                               表示故障，对应故障类型为：
                               3——输出轴校准异常；
                               4——传感器输出异常；
                               5——电机编码器校准异常；
                               8——超压；        9——欠压；
异常状态              红灯闪烁
                               A——过电流；       B——MOS 过温；
                               C——电机线圈过温；    D——通讯丢失；
                               E——过载；
                               注：可通过反馈帧，或通过达妙科技调试助手界面显示，
                               查看发生何种故障。

                         第 9 页 共 45 页

             深圳市达妙科技有限公司 DM-J4310-2EC V1.1 使用说明书 V1.2

工作模式

◈ MIT 模式
  MIT 模式是为了兼容原版 MIT 模式所设计，可以在实现无缝切换的同时，能够灵活设定控制范围（P_
MAX，V_MAX，T_MAX），电调将接收到的 CAN 数据转化成控制变量进行运算得到扭矩值作为电流环的电流
给定，电流环根据其调节规律最终达到给定的扭矩电流。其控制示意框图如下：

  根据 MIT 模式可以衍生出多种控制模式，如 kp=0，kd 不为 0 时，给定 v_des 即可实现匀速转动；
kp=0，kd=0，给定 t_ff 即可实现给定扭矩输出。
  注意：对位置进行控制时，kd 不能赋 0，否则会造成电机振荡，甚至失控。

◈ 位置速度模式
  位置串级模式是采用三环串联控制的模式，位置环作为最外环，其输出作为速度环的给定，而速度环的输
出作为内环电流环的给定，用以控制实际的电流输出，其控制示意框图如下：

  p_des 为控制的目标位置，v_des 是用来限定运动过程中的最大绝对速度值。
  位置串级模式如使用调试助手推荐的控制参数控制，可以达到较好的控制精度，控制过程相对柔顺，但响
应时间相对较长。可配置的相关参数除 v_des 外，另有加 / 减速度进行设定，如控制过程中产生额外的振荡可
提高加 / 减速度。
  注意：p_des，v_des 单位分别为 rad 和 rad/s，数据类型为 float，阻尼因子必须设置为非 0 的正数，
可参考速度模式的注意事项。

◈ 速度模式
  速度模式能让电机稳定运行在设定的速度，其控制示意框图如下：

  注意：v_des 单位为 rad/s，数据类型为 float。

                             第 10 页 共 45 页

                 深圳市达妙科技有限公司 DM-J4310-2EC V1.1 使用说明书 V1.2

◈ 力位混控模式
  力位混控模式为在位置速度模式控制的基础上动态控制输出扭矩的大小，其控制框图如下：

  在速度环的输出指令后增加了电流指令饱和环节，使得电流环的给定限定在给定范围内。

◈ 模式修改
  模式切换可以通过上位机使用串口进行设定，只需选择相应的模式，点击“写参数”即可，通过该方法设
置成功后，电机会自动进行复位，模式将被储存在电机驱动器内部，重新上电不会丢失。
  此外，还可以通过 CAN 接口来修改，需要修改模式寄存器的内容，具体详见下一章中“模式切换”小节，
该方法设置后，电机不会复位，但会使以下五个变量归零：
  1. 位置命令值
  2. 速度命令值
  3. 扭矩命令值（MIT 模式）
  4.kp（MIT 模式）
  5.kd（MIT 模式）
  在不发送“保存参数”的命令下，模式不会进行存储，掉电后会丢失，重新上电后会载入上次保存的模式。

CAN 通信
  电机完成校准、标定以及参数设置后即可使用，控制使用 CAN 标准帧（STD）格式，默认波特率为
1Mbps，可使用指令更改切换成不同的波特率，具体参见 CAN 波特率修改章节。按功能可分为接收帧和反馈
帧，接收帧为接收到的控制数据，用于实现对电机的命令控制；反馈帧为电机向上层控制器发送电机的状态数
据，反馈行为为问询式的，只要驱动接收到的帧 ID 与电机设定的 CAN ID 匹配（低 8 位进行校验，高 3 位忽略）
时，驱动器即向总线发送当前的状态数据。根据电机选定的不同模式，其接收帧帧格式定义以及帧 ID 各不相同，
但各种模式下的反馈帧是相同的。

◈ 修改波特率
  波特率修改可以通过上位机使用串口进行设定，只需选择相应的波特率，点击“写参数”即可，通过该方
法设置成功后，电机会自动进行复位，波特率将被储存在电机驱动器内部，重新上电不会丢失。
  另一种方式是通过 CAN 接口进行修改，通过写入波特率寄存器的值来完成，详见本章“CAN 波特率修改”
小节。
  注意：使用 CAN 修改波特率，在总线上有多个设备时会导致失败，因此需谨慎，强烈建议在装机前先配
置好波特率。

◈ 反馈帧

                                第 11 页 共 45 页

                  深圳市达妙科技有限公司 DM-J4310-2EC V1.1 使用说明书 V1.2

  反馈帧 ID 由调试助手设置（Master ID），默认为 0，主要反馈电机的位置，速度和扭矩信息，其帧格式定义为：

反馈报文       D[0]       D[1]     D[2]        D[3]         D[4]       D[5]     D[6]    D[7]
                                                      VEL[3:0]|
MST_ID   ID|ERR<<4 POS[15:8] POS[7:0]    VEL[11:4]                T[7:0]   T_MOS   T_Rotor
                                                       T[11:8]

  其中：
  ID 表示控制器的 ID，取 CAN_ID 的低 8 位。
  ERR 表示状态，对应状态类型为：
  0——失能（上电后默认状态）；
  1——使能；
  3——输出轴校准异常；
  4——传感器输出异常；
  5——电机编码器校准异常；
  8——超压；
  9——欠压；
  A——过电流；
  B——MOS 过温；
  C——电机线圈过温；
  D——通讯丢失；
  E——过载；
  POS 表示电机的位置信息；
  VEL 表示电机的速度信息；
  T 表示电机的扭矩信息；
  T_MOS 表示驱动上 MOS 的平均温度，单位℃；
  T_Rotor 表示电机内部线圈的平均温度，单位℃。
  位置、速度和扭矩采用线性映射的关系将浮点型数据转换成有符号的定点数据，其中位置采用 16 位数据，速
度和扭矩均使用 12 位，见下图：

   图 1：速度线性映射图                   图 2：位置线性映射图                          图 3：扭矩线性映射图

  【注意】：

  ①上电后，电机位置输出限定在 [-π,π]rad 之间。

  ②位置的单位为 rad( 弧度 )，下述对位置的描述均为此定义，不再赘述。

  ③速度的单位为 rad/s( 弧度每秒 )，下述对速度的描述均为此定义，不再赘述。

  ④扭矩的单位为 Nm，下述对扭矩的描述均为此定义，不再赘述。

                                      第 12 页 共 45 页

                      深圳市达妙科技有限公司 DM-J4310-2EC V1.1 使用说明书 V1.2

◈ MIT 模式下的控制帧

 控制报文         D[0]       D[1]        D[2]         D[3]        D[4]          D[5]       D[6]       D[7]
             p_des      p_des       v_des     v_des[3:0]|      Kp             Kd      Kd[3:0]|     t_ff
   ID
             [15:8]      [7:0]      [11:4]     Kp[11:8]       [7:0]         [11:4]   t_ff[11:8]   [7:0]

   帧 ID 等于设定的 CAN ID 值；

   P_des：位置给定；

   V_des：速度给定；

   Kp：位置比例系数；

   Kd：位置微分系数；

   T_ff：转矩给定值。

   各参数符合上一节的映射关系，其中 p_des，v_des，t_ff 的范围可由调试助手进行设定，Kp 的范围为 [0，

500]，Kd 的范围为 [0，5]。

   标准 CAN 数据一帧只有 8 个字节，MIT 的控制命令格式将 Position、Velocity、Kp、Kd、Torque 五个

参数按位组合在 8 个字节中。其中：Position 占用 2 个字节 16 位、Velocity 占用 12 位、Kp 占用 12 位、Kd

占用 12 位。

   MIT 命令采用浮点数据等比例转换成整数发送到驱动器，驱动器再将接收到的整数等比例转换成浮点数据。

这部分转换使用到 uint_to_float、float_to_uint 两个转换函数进行转换，该部分具体实现如下所示：

   1. float uint_to_float(int x_int, float x_min, float x_max, int bits){

   2. /// converts unsigned int to float, given range and number of bits ///

   3. float span = x_max - x_min

   4. float offset = x_min

   5. return ((float)x_int)*span/((float)((1<<bits)-1)) + offset

   6. }

   1. int float_to_uint(float x, float x_min, float x_max, int bits){

   2. /// Converts a float to an unsigned int, given range and number of bits ///

   3. float span = x_max - x_min

   4. float offset = x_min

   5. return (int) ((x-offset)*((float)((1<<bits)-1))/span)

   6.   }

   这两个转换函数需要首先确定两个等比例转换的最大最小值，这两个值可以在顶部菜单栏“参数设置”页

面查询，其中 KP、KD 的最大最小值默认分别为 0.0~500.0、0.0~5.0。Pos、Vel、Torque 如下图所示分别预

设为 ±12.5、±30、±10，这三个参数可以根据电机的实际参数进行调整。但发送控制命令时，一定要与设

                                             第 13 页 共 45 页

                       深圳市达妙科技有限公司 DM-J4310-2EC V1.1 使用说明书 V1.2

定值保持一致，否则会控制命令会发生等比例缩放。

◈ 位置速度模式下的控制帧

 控制报文           D[0]       D[1]           D[2]        D[3]       D[4]           D[5]           D[6]           D[7]

 0x100+ID                         p_des                                                v_des

   帧 ID 为设定的 CAN ID 值加上 0x100 的偏移；
   P_des：位置给定，浮点型，低位在前，高位在后；
   V_des：速度给定，浮点型，低位在前，高位在后；
   此处发送命令的 CAN ID 是 0x100+ID。速度给定是运行过程中限定的最高速度值。

◈ 速度模式下的控制帧

    控制报文                    D[0]                     D[1]                  D[2]                        D[3]

    0x200+ID                                                 v_des

   帧 ID 为设定的 CAN ID 值加上 0x200 的偏移；
   V_des：速度给定，浮点型，低位在前，高位在后；
   此处发送命令的 CAN ID 是 0x200+ID。

◈ 力位混控模式下的控制帧

控制报文           D[0]       D[1]           D[2]        D[3]        D[4]           D[5]           D[6]           D[7]

0x300+ID                         p_des                                  v_des                         i_des

   P_des：位置给定，单位为 rad，浮点类型，低位在前，高位在后；
   V_des：限速值，单位 rad/s，放大 100 倍，类型为无符号 16 位，低位在前，高位在后，范围为 0-10000，
超过 10000 会限制在 10000，故对应的实际速度限定幅值为 0~100rad/s；
   I_des：扭矩电流限定标幺值，放大 10000 倍，类型为无符号 16 位，，低位在前，高位在后，范围为 0-10000，
超过 10000 会限制在 10000，对应的实际电流限定标幺幅值为 0-1.0。
   电流标幺值：实际电流值除以最大相电流值（见上电打印）。

                                                 第 14 页 共 45 页

                    深圳市达妙科技有限公司 DM-J4310-2EC V1.1 使用说明书 V1.2

◈ 使能
  上电自检完毕后需发送“使能”命令才可以进行控制。“使能”帧属于控制帧，帧 ID 如前所述，不同的
是数据段，无论处于哪种模式，“使能”的数据定义是相同的，如下：

  D[0]       D[1]           D[2]            D[3]          D[4]          D[5]            D[6]               D[7]

                                           0xFF                                                           0xFC

◈ 失能
  失能为电机上电默认状态，此时电机三相端子电压波形相同，均为电源电压的 50% 调制波。“失能”帧
属于控制帧，帧 ID 如前所述，数据段定义如下：

  D[0]       D[1]           D[2]            D[3]          D[4]          D[5]            D[6]               D[7]

                                           0xFF                                                           0xFD

◈ 保存位置零点
  “保存位置零点”帧属于控制帧，该命令会将当前输出轴的位置设定成零点，并将位置给定值设置成 0，
帧 ID 如前所述，数据段定义如下：

  D[0]       D[1]           D[2]            D[3]          D[4]          D[5]            D[6]               D[7]

                                           0xFF                                                           0xFE

◈ 清除错误
  电机出现过热等错误时，发送“清除”命令可以清除错误。“清除”帧属于控制帧，帧 ID 如前所述，数
据段定义如下：

  D[0]       D[1]           D[2]            D[3]          D[4]          D[5]            D[6]               D[7]

                                           0xFF                                                           0xFB

◈ 读取参数

  报文 ID              属性                   D[0]              D[1]               D[2]                      D[3]

   0x7FF             STD            CANID_L               CANID_H              0x33                      RID

  RID 为寄存器地址，见本说明书 < 寄存器列表及范围 > 章节。

  读取成功后，会返回该寄存器的数据，帧格式如下：

报文 ID      属性        D[0]          D[1]            D[2]          D[3]     D[4]        D[5]        D[6]          D[7]

MST_ID     STD      CANID_L    CANID_H             0x33          RID                         数据

                                             第 15 页 共 45 页

                  深圳市达妙科技有限公司 DM-J4310-2EC V1.1 使用说明书 V1.2

  数据为浮点型数据或无符号整型，占用 32 位共 4 字节，低位 D4，最高位为 D7，下同。

◈ 写入参数

报文 ID       属性     D[0]      D[1]          D[2]        D[3]   D[4]         D[5]        D[6]          D[7]

 0x7FF      STD   CANID_L   CANID_H        0x55        RID                        数据

  RID 如上，写成功后会返回写入的数据，帧格式与发送的相同。

报文 ID       属性     D[0]      D[1]          D[2]        D[3]   D[4]         D[5]        D[6]          D[7]

MST_ID      STD   CANID_L   CANID_H        0x55        RID                        数据

  写寄存器数据立即生效，但无法进行存储，掉电后丢失，需要发送存储参数的命令，将修改的参数全部写

入片内。

◈ 存储参数

   报文 ID           属性               D[0]           D[1]          D[2]                         D[3]

   0x7FF           STD         CANID_L            CANID_H        0xAA                     0x01

  写入成功后，返回格式为：

   报文 ID           属性            D[0]              D[1]          D[2]                     D[3]

   MST_ID          STD         CANID_L            CANID_H        0xAA                     0x01

  【注意】：
  ①存储参数只在失能模式下生效。
  ②存储参数时将一次性保留全部参数。
  ③该操作将参数写入片内 flash 中，每次操作时间最大为 30ms，请注意留出足够的时间。
  ④ flash 擦写次数约 1 万次，请不要频繁发送“存储参数”指令。

◈ 模式切换
  支持多种模式互相切换，目前支持的控制模式如下：

                   编码                                            模式

                    1                                                MIT

                    2                                          位置速度

                    3                                            速度

                    4                                          力位混控

  通过修改模式寄存器 (0x0A) 的值，即可修改模式，模式切换时，电机首先清零指令值，包括位置、速度、

                                       第 16 页 共 45 页

                深圳市达妙科技有限公司 DM-J4310-2EC V1.1 使用说明书 V1.2

以及 MIT 模式里的扭矩前馈和 KP，KD 的值。
  由一种模式切换到位置控制的模式时，为防止冲击，建议先读取精确的位置（寄存器 0x50 的值）后，再
考虑切换，尽量在电机零速的时候进行切换。
  模式修改后，不会存入 flash 中，掉电会丢失，重新上电后，控制模式设置为上次存入 flash 中的模式。

◈ CAN 波特率修改
  通过向波特率寄存器 ( 地址为 0x23) 写入特定的数据，可以修改当前的 CAN 通讯波特率，支持特定波特
率修改，目前可支持的波特率如下：

                   编码                                   波特率

                   0                                    125K

                   1                                    200K

                   2                                    250K

                   3                                    500K

                   4                                    1M

                   5                                    2M

                   6                                    2.5M

                   7                                    3.2M

                   8                                    4M

                   9                                    5M

  修改波特率成功后，驱动器先以原波特率反馈数据，之后以新的波特率进行通讯。上电后电机先判断存储
的波特率，若大于 5Mbps，则自动默认为 1Mbps，对于大于 1Mbps( 不包含 1Mbps) 将自动变成 CAN FD 功
能；若波特率小于等于 1Mbps，自动变成 CAN 2.0B。设置成 CAN FD 的电机仍可以接受到 CAN 2.0B 数据帧，
但发送反馈帧时采用 CAN FD，因此上层控制器将接收不到反馈数据，并且驱动器会不断报错。采用 CAN 2.0B
的控制器设置错 ID 后，仍可以通过修改波特率的命令改回波特率。
  注意：使用 CAN 修改波特率，在总线上有多个设备时会导致失败，因此需谨慎，强烈建议在装机前先配
置好波特率。

◈ 寄存器列表及范围

 地址 (HEX)   地址 (DEC)      变量              描述       读写            范围         类型

   0x00        0        UV_Value        低压保护值      RW        (10.0,fmax]    float

   0x01        1        KT_Value         扭矩系数      RW          [0.0,fmax]   float

   0x02        2        OT_Value        过温保护值      RW          [80.0,200)   float

                                   第 17 页 共 45 页

               深圳市达妙科技有限公司 DM-J4310-2EC V1.1 使用说明书 V1.2

地址 (HEX)   地址 (DEC)      变量              描述       读写       范围           类型

  0x03        3        OC_Value        过流保护值      RW     (0.0,1.0)     float

  0x04        4          ACC             加速度      RW    (0.0,fmax)     float

  0x05        5          DEC             减速度      RW    [-fmax,0.0)    float

  0x06        6        MAX_SPD          最大速度      RW    (0.0,fmax]     float

  0x07        7        MST_ID           反馈 ID     RW    [0,0x7FF]      uint32

  0x08        8         ESC_ID          接收 ID     RW    [0,0x7FF]      uint32

  0x09        9        TIMEOUT        超时警报时间      RW    [0,2^32-1]     uint32

  0x0A        10      CTRL_MODE         控制模式      RW       [0,4]       uint32

  0x0B        11        Damp          电机粘滞系数      RO        —          float

  0x0C        12        Inertia       电机转动惯量      RO        —          float

  0x0D        13       hw_ver            保留       RO        —          uint32

  0x0E        14        sw_ver         软件版本号      RO        —          uint32

  0x0F        15          SN             保留       RO        —          uint32

  0x10        16         NPP           电机极对数      RO        —          uint32

  0x11        17          Rs           电机相电阻      RO        —          float

  0x12        18          Ls           电机相电感      RO        —          float

  0x13        19         Flux          电机磁链值      RO        —          float

  0x14        20          Gr           齿轮减速比      RO        —          float

  0x15        21        PMAX          位置映射范围      RW    (0.0,fmax]     float

  0x16        22        VMAX          速度映射范围      RW    (0.0,fmax]     float

  0x17        23        TMAX          扭矩映射范围      RW    (0.0,fmax]     float

  0x18        24        I_BW         电流环控制带宽      RW   [100.0,1.0e4]   float

  0x19        25       KP_ASR          速度环 Kp     RW    [0.0,fmax]     float

  0x1A        26        KI_ASR         速度环 Ki     RW    [0.0,fmax]     float

  0x1B        27       KP_APR          位置环 Kp     RW    [0.0,fmax]     float

  0x1C        28       KI_APR          位置环 Ki     RW    [0.0,fmax]     float

  0x1D        29       OV_Value        过压保护值      RW       TBD         float

                                  第 18 页 共 45 页

               深圳市达妙科技有限公司 DM-J4310-2EC V1.1 使用说明书 V1.2

地址 (HEX)   地址 (DEC)     变量              描述       读写       范围            类型

  0x1E        30       GREF          齿轮力矩效率      RW     (0.0,1.0]      float

  0x1F        31       Deta         速度环阻尼系数      RW     [1.0,30.0]     float

  0x20        32       V_BW         速度环滤波带宽      RW    (0.0,500.0)     float

  0x21        33       IQ_c1        电流环增强系数      RW   [100.0, 1.0e4]   float

  0x22        34       VL_c1        速度环增强系数      RW    (0.0,1.0e4]     float

  0x23        35      can_br        CAN 波特率代码    RW       [0,9]        uint32

  0x24        36      sub_ver          子版本号      RO        —           uint32

  0x25        37      Boot_ver       Boot 版本号    RO        —           uint32

  0x37        55        dir             方向       RO        —           float

  0x38        56       m_off        电机侧角度偏移      RO        —           float

  0x3B        59       Imax         驱动板最大电流      RO        —           float

  0x3C        60       VBus            电源电压      RO        —           float

  0x3D        61       Tpcb            驱动温度      RO        —           float

  0x3E        62       Tmtr          电机线圈温度      RO        —           float

  0x3F        63      I_U_OFF        U 相电流偏置     RO        —           float

  0x40        64      I_V_OFF        V 相电流偏置     RO        —           float

  0x41        65      I_W_OFF        W 相电流偏置     RO        —           float

  0x50        80        p_m          电机当前位置      RO        —           float

  0x51        81        xout          输出轴位置      RO        —           float

 注：
 1.RW：可读写。
 2.RO：只读。
 3. 电机输出轴位置是指使用转子折算到输出轴的位置，单位为 rad。
 4. 输出轴位置是指采用电机输出轴编码器计算得出的位置，单位为 rad。

电机调试流程
 请使用 V2.0.3.6 及以上的上位机版本进行调试，以下以 V2.0.3.4 版本上位机进行调试流程演示。

◈ 连接设备

                                 第 19 页 共 45 页

           深圳市达妙科技有限公司 DM-J4310-2EC V1.1 使用说明书 V1.2

  首先，连接电机的串口、CAN 口以及电源接口。电脑端打开调试助手软件，选择相应的串口设备并打开串口。

  此时给电机供电，串口会打印下述信息。Control Mode : 指示当前驱动模式。不同的模式采用不同的命
令格式（参考 CAN 通信章节）。

◈ 电机侧编码器校准
  电机侧编码器校准目的主要是修正传感器的安装误差，过程中电机会正向反向转动一个转子周期，请保证
电机可以自由转动，电机需要空载运行，否则可能造成校准失败。电机出厂已进行校准操作，并写在电机内，
如非异常情况，可以直接使用，无需再进行校准。以下提供校准的操作步骤，在电机更换驱动板，异常震动等
非正常状态，可以先进行校准再运行。
  步骤 1：电机侧编码器校准

                          第 20 页 共 45 页

        深圳市达妙科技有限公司 DM-J4310-2EC V1.1 使用说明书 V1.2

点击校准，电机会先转动，转动完毕后向调试助手返回极对数。

之后电机会先自动进行参数识别，此过程中电机会有旋转运动，请注意固定好电机，以免发生事故。

参数识别完成后，电机会自动进行传感器校准，并显示电机的传感器波形图，如下：

注意：红色的曲线最大值不要明显超过蓝色的曲线，否则将会造成失败，失败后重新校准即可。

                       第 21 页 共 45 页

            深圳市达妙科技有限公司 DM-J4310-2EC V1.1 使用说明书 V1.2

  步骤 2：校准完成后，会自动上传校准值，示例如下：

  步骤 3：校准数据排查与存储
  应当特别关注“Compensation Data 补偿”的值，建议不要超过 ±300，若超过 300 可能
  有几个原因：
  ① 极对数识别错误；
  ② 电机阻力过大，导致卡顿；
  ③ 传感器安装不规范；
  步骤 4：请从以上几点进行排查。

◈ 参数标定
  参数辨识主要识别电机的相电阻、相电感以及磁链等重要参数。电机出厂已进行标定操作，并写在电机内，
可以直接使用，无需再重新标定，以下提供标定的步骤。
  点击“参数设置”标签卡，再点击“参数标定”按钮，驱动器进入辨识步骤。期间电机会转动，应保持空
载状态，并固定好电机。

                           第 22 页 共 45 页

          深圳市达妙科技有限公司 DM-J4310-2EC V1.1 使用说明书 V1.2

  辨识完成后，会自动上传辨识的结果。
  粘滞系数仅作为参考，可多次标定。
  【注意】以上参数除粘滞系数外不能出现负值，若出现负值，请确认电机状态后再进行标定。

◈ 输出轴编码器校准
  双编码器电机需要进行输出轴编码器校准，用来提升输出轴编码器准确度。过程中电机会正向转动一周，
请保证电机可以自由转动，确保电机空载运行，否则可能造成校准误差过大。电机出厂已进行输出轴编码器校
准操作，并写在电机内，如非异常情况，可以直接使用，无需再进行输出轴编码器校准。以下提供输出轴编码
器校准的操作步骤，在电机更换驱动板，输出位置变化等非正常状态，可以先进行输出轴编码器校准再运行。
下图仅为参考示例图，图中参数与该电机无关。

  步骤 1：输出轴编码器校准
  点击校准按钮边的滑块至显示“输出轴编码器”状态，再点击校准。

                         第 23 页 共 45 页

           深圳市达妙科技有限公司 DM-J4310-2EC V1.1 使用说明书 V1.2

  电机开始旋转，并上传编码器原始数据波形，见下图：

  步骤 2：校准完成后，会自动上传显示校准值，如下：

  步骤 3：校准数据校验
  校准完成后，驱动器会自动进行数据校验，如校验数据偏差过大，则会报错，错误类型为 3，红灯闪烁。
一般情况下出错是由于输出轴编码器异常导致，可以联系售后解决。

                          第 24 页 共 45 页

           深圳市达妙科技有限公司 DM-J4310-2EC V1.1 使用说明书 V1.2

◈ 串口读写参数

  1. 读参数
  在“参数设置”标签卡下，点击“读参数”按钮，驱动器会将驱动器存储使用的参数上传到调试助手，请
仔细核对参数。

                          第 25 页 共 45 页

             深圳市达妙科技有限公司 DM-J4310-2EC V1.1 使用说明书 V1.2

  读取到的参数包括：
  （1）驱动参数：驱动的参数设置部分
  ・ 极对数：电机的极对数，通过校准可以自动得出，切勿修改；
  ・ 欠压：若电源电压低于设定值，驱动器将无法控制电机运转，默认为 20V；
  ・ 过压：设定驱动器工作的电压上限，电机上电时会进行电源电压采集，当采集到的电压超过此值，驱
动器将报错并退出使能，上电时若出现超压，则持续报错；
  ・ 加速度 / 减速度：在非 MIT 模式下使用，用以限定驱动器的加 / 减速度，电机转子参数，单位为
Krad/s^2，其中，减速度为负数；
  ・ 减速比：电机的减速比，主要影响到电机输出的转速和位置，间接影响电机的转矩反馈信息，切勿修改；
  ・ 过温：电机线圈温度保护值，根据使用需求设定，建议不超过 100℃，过温后驱动器退出使能状态，
进入失能状态，并报错；
  ・ CAN_ID：驱动器 ID 号，CAN 命令使用，16 进制，建议设置成小于 16，以免与报错类型冲突；
  ・ Master ID：驱动器反馈信息使用的帧 ID 号，16 进制；
  ・ CAN Timeout：CAN 通讯超时时间设置，整数 32 位，表示多少个计数周期后仍未检测到 CAN 命令，
进行电机保护，一个计数周期为 50us，只在电机使能时生效；
  ・ 限速：限定电机转子（减速前）的最大运行速度，单位为 rad/s；
  ・ 过流：用以限定电机的最大相电流，百分比数；
  ・ CAN 波特率：配置 CAN 波特率，支持 125Kbps-5Mbps；
  ・ Ki_current( 电流环增强系数 )：电流环辅助控制参数，不建议修改；
  ・ fbw ( 速度环滤波带宽 )：转速滤波带宽，单位为 Hz；
  ・ 子版本号：固件的子版本号；
  ・ Ki_speed( 速度环增强系数 )：速度环辅助控制参数，建议可调范围为 200-800。
  注意：点击读参数成功后，会同步更新调试界面的参数，如 PMAX，ID 等。
  （2）电机参数：电机参数部分
  此部分参数是由驱动器自动辨识得出（更换驱动板需要标定一次参数，此部分参数自动保存到驱动器中）。
  （3）控制幅值：驱动命令参数范围设定
  ・ PMAX：在 MIT 模式下，作为电机接收命令的映射值，其它模式下为电机反馈信息的映射值。映射规
则请查看 CAN 通信章节；
  ・ VMAX：同 PMAX；
  ・ TMAX：同 PMAX；
  ・ KT_OUT：电机的扭矩系数，在电机参数辨识准确的情况下，设置为 0；
  ・ 齿轮系数：齿轮力矩传动系数，小于等于 1.0；
  ・ 阻尼因子：电流环与速度环控制带宽比，未使用到。
  （4）控制设置
  ・ 控制模式：MIT 模式、位置速度模式、速度模式、力位混控模式；
  ・ 电流带宽：设置电流环的增益系数，默认 1000；

                            第 26 页 共 45 页

            深圳市达妙科技有限公司 DM-J4310-2EC V1.1 使用说明书 V1.2

  ・ 速度 KP/KI，位置 KP/KI：速度环，位置环的参数。
  写完参数后，请“读参数”更新到上位机，保证反馈数据无误。

  2. 写参数
  核对驱动参数、控制幅值、控制设置等参数，对需要修改的参数进行修改，最后点击“写参数”将修改后
的参数保存至驱动器中。
  点击“写参数”按钮芯片会自动复位，因此在使用“写参数”时请确保电机处于“失能”状态，以防止发
生安全事故。

  【注意】：
  ① 请勿修改极对数和减速比参数。
  ② 点击“写参数”后，驱动器将自动软件重启，无需外部重启电源。
  ③ 建议写完参数后，读参数更新到上位机，保证反馈数据无误。

◈ 调试
  此功能仅在连接 CAN 接口的情况下方可操作，只可以调试单个电机，操作前需连接 CAN 线至驱动器板。
调试前需确认先确认好接线线序以及当前控制模式，根据不同模式选择调试页面中的子标签卡。

  1. 控制模式的选择与确认
  点击调试助手“参数设置”，在控制设置中点击“控制模式”，该电机可选择 MIT、位置速度、速度、力
位混控模式四种模式，然后点击“写参数”进行控制模式设置。

                           第 27 页 共 45 页

        深圳市达妙科技有限公司 DM-J4310-2EC V1.1 使用说明书 V1.2

修改控制模式时，将弹出提示窗口：“写参数成功”。

（1）根据上电串口打印数据判断控制模式，箭头指向的模式即为当前驱动的控制模式。

（2）或者根据参数设定页面上重新读参数后显示的信息，判断驱动器的控制模式。

写完参数后，请读参数更新到上位机，保证反馈数据无误。

                       第 28 页 共 45 页

              深圳市达妙科技有限公司 DM-J4310-2EC V1.1 使用说明书 V1.2

  2. MIT 模式
  （1）参考控制模式的选择与确认，选择当前为 MIT 模式，确定当前控制模式，在调试页面中选择对应的
MIT 子标签卡。

  （2）确保 CAN ID 正确（可通过串口打印信息或者参数设置页面获取，也可以通过调试页面读取、设定
按钮设定）。

  （3）MIT 模式有三种控制方法：速度、位置、力矩。
  ① 速度控制
  第一步，电机模式栏点击“使能”按钮。此时驱动器绿色灯亮起，表示电机已使能。

                             第 29 页 共 45 页

            深圳市达妙科技有限公司 DM-J4310-2EC V1.1 使用说明书 V1.2

  第二步，给定速度让电机按照给定速度运行。
  例如：速度给定 5rad/s，KD 给 1N*s/r 其余全部给 0，并勾选“定时发送”框，依次点击“更新”按钮和“发
送”按钮，可在调试界面查看参数曲线变化图。注意固定电机。

  根据调试需求，需要修改控制参数查看调试变化，在原界面直接对参数进行修改，并保持勾选“定时发送”，
点击“更新”按钮即可进行调试。
  调试助手界面对当前电机和驱动的温度以及电机运行状态实时显示，也可通过反馈帧查看，反馈帧格式以
及状态类型请查看“ 反馈帧”章节。

                           第 30 页 共 45 页

           深圳市达妙科技有限公司 DM-J4310-2EC V1.1 使用说明书 V1.2

  第三步，退出调试时，依次点击“停止”和“失能”按钮。驱动器红色灯亮起，表示退出电机模式。

  ② 位置控制
  第一步，在电机模式栏点击“使能”按钮。此时驱动器绿色灯亮起，表示电机已使能。

  第二步，给定位置让电机旋转到指定位置。
  此时应注意电机初始位置，对控制参数栏中的“位置”参数给定数值时，避免与初始位置差距过大，引起
电机冲击。
  可通过控制命令栏点击“保存零点”将电机当前位置设置为零点，方便“位置”参数设置。

                          第 31 页 共 45 页

             深圳市达妙科技有限公司 DM-J4310-2EC V1.1 使用说明书 V1.2

  例如，给定参数：位置给定 3.14rad，KP 给定 2.0N/r，KD 给 1N*s/r 其余全部给 0，并勾选“定时发送”
框，依次点击“更新”按钮和“发送”按钮，可在调试界面查看参数曲线变化图。注意固定电机。

  根据调试需求，需要修改控制参数查看调试变化，在原界面直接对参数进行修改，并保持勾选“定时发送”，
点击“更新”按钮即可进行调试。
  调试助手界面对当前电机和驱动的温度以及电机运行状态实时显示，也可通过反馈帧查看，反馈帧格式以
及状态类型请查看“反馈帧”章节。

                            第 32 页 共 45 页

         深圳市达妙科技有限公司 DM-J4310-2EC V1.1 使用说明书 V1.2

第三步，退出调试时，依次点击“停止”和“使能”按钮。驱动器红色灯亮起，表示退出电机模式。

③ 力矩控制
第一步，电机模式栏点击“使能”按钮。此时驱动器绿色灯亮起，表示电机已使能。

                        第 33 页 共 45 页

          深圳市达妙科技有限公司 DM-J4310-2EC V1.1 使用说明书 V1.2

  第二步，给定力矩进行电机调试。
  注意：空载情况下，即使给定很小的力矩，电机也会加速到最大转速旋转。
  例如，给定参数：转矩设定为 1N*m，其余全部给 0，并勾选“定时发送”框，依次点击“更新”按钮和“发
送”按钮，可在调试界面查看参数曲线变化图。注意固定电机。

  根据调试需求，需要修改控制参数查看调试变化，在原界面直接对参数进行修改，并保持勾选“定时发送”，
点击“更新”按钮即可进行调试。
  调试助手界面对当前电机和驱动的温度以及电机运行状态实时显示，也可通过反馈帧查看，反馈帧格式以
及状态类型请查看“反馈帧”章节。

                         第 34 页 共 45 页

          深圳市达妙科技有限公司 DM-J4310-2EC V1.1 使用说明书 V1.2

  第三步，退出调试时，依次点击“停止”和“使能”按钮。驱动器红色灯亮起，表示退出电机模式。

  3. 位置速度模式
  （1）调试位置速度模式需要在参数页面将电机模式切换成位置速度模式，再点击写参数后生效，在调试
页面中选择对应的“位置”子标签卡。

  （2）确保 CAN ID 正确（可通过串口打印信息或者参数设置页面获取，也可以通过调试页面读取、设定
按钮设定）。

                         第 35 页 共 45 页

           深圳市达妙科技有限公司 DM-J4310-2EC V1.1 使用说明书 V1.2

  （3）电机模式栏点击“使能”按钮。此时驱动器绿色灯亮起，表示电机已使能。

  （4）设定参数，电机按照设定速度运转到指定位置。
  设置参数前，需注意电机的初始位置，以此为参考对参数进行设置。

  例如，设定参数：位置为 10rad，速度为 5rad/s。并勾选“定时发送”框，依次点击“更新”按钮和“发
送”按钮，可在调试界面查看参数曲线变化图。注意固定电机。

                          第 36 页 共 45 页

          深圳市达妙科技有限公司 DM-J4310-2EC V1.1 使用说明书 V1.2

  根据调试需求，需要修改控制参数查看调试变化，在原界面直接对参数进行修改，并保持勾选“定时发送”，
点击“更新”按钮即可进行调试。
  调试助手界面对当前电机和驱动的温度以及电机运行状态实时显示，也可通过反馈帧查看，反馈帧格式以
及状态类型请查看“反馈帧”章节。

  （5）退出调试时，依次点击“停止”和“失能”按钮。驱动器红色灯亮起，表示退出电机模式。

                         第 37 页 共 45 页

            深圳市达妙科技有限公司 DM-J4310-2EC V1.1 使用说明书 V1.2

  4. 速度模式
  （1）参考控制模式的选择与确认，选择当前为速度模式，确定当前控制模式，在调试页面中选择对应的“速
度”子标签卡。

  （2）确保 CAN ID 正确（可通过串口打印信息或者参数设置页面获取，也可以通过调试页面读取、设定
按钮设定）。

  （3）电机模式栏点击“使能”按钮。此时驱动器绿色灯亮起，表示电机已使能。

  （4）设定参数，电机按照设定速度运转。例如，设定参数：速度为 5rad/s。
  勾选“定时发送”框，依次点击“更新”按钮和“发送”按钮，可在调试界面查看参数曲线变化图。注意
固定电机。

                           第 38 页 共 45 页

            深圳市达妙科技有限公司 DM-J4310-2EC V1.1 使用说明书 V1.2

  根据调试需求，需要修改控制参数查看调试变化，在原界面直接对参数进行修改，并保持勾选“定时发送”，
点击“更新”按钮即可进行调试。
  调试助手界面对当前电机和驱动的温度以及电机运行状态实时显示，也可通过反馈帧查看，反馈帧格式以
及状态类型请查看“反馈帧”章节。

  （5）退出调试时，先发送 0 速度让电机停止，再依次点击“停止”和“失能”按钮。驱动器红色灯亮起，
表示退出电机模式。

                           第 39 页 共 45 页

          深圳市达妙科技有限公司 DM-J4310-2EC V1.1 使用说明书 V1.2

  5. 力位混控模式
  （1）调试力位混控模式需要在参数页面将电机模式切换成 PVT 模式，再点击写参数后生效，在调试页面
中选择对应的“PVT”子标签卡。

  （2）确保 CAN ID 正确（可通过串口打印信息或者参数设置页面获取，也可以通过调试页面读取、设定
按钮设定）。

  （3）电机模式栏点击“使能”按钮。此时驱动器绿色灯亮起，表示电机已使能。

  （4）设定参数，电机按照设定速度运转到指定位置。
  设置参数前，需注意电机的初始位置，以此为参考对参数进行设置。

                         第 40 页 共 45 页

           深圳市达妙科技有限公司 DM-J4310-2EC V1.1 使用说明书 V1.2

  例如，设定参数：位置为 10rad，速度为 5rad/s，电流 0.2%FS。并勾选“定时发送”框，依次点击“更
新”按钮和“发送”按钮，可在调试界面查看参数曲线变化图。注意固定电机。

  根据调试需求，需要修改控制参数查看调试变化，在原界面直接对参数进行修改，并保持勾选“定时发送”，
点击“更新”按钮即可进行调试。

                          第 41 页 共 45 页

          深圳市达妙科技有限公司 DM-J4310-2EC V1.1 使用说明书 V1.2

  调试助手界面对当前电机和驱动的温度以及电机运行状态实时显示，也可通过反馈帧查看，反馈帧格式以
及状态类型请查看“反馈帧”章节。

  （5）退出调试时，先确保电机停下，再依次点击“停止”和“失能”按钮。驱动器红色灯亮起，表示退
出电机模式。

                         第 42 页 共 45 页

           深圳市达妙科技有限公司 DM-J4310-2EC V1.1 使用说明书 V1.2

固件版本查看与升级

◈ 版本查看
  连接电机的串口、CAN 口以及电源接口，选择相应的串口设备并打开串口，点击“读版本”，即可查看
到当前驱动器的软件版本号。
  对固件升级时请先读取当前版本，若无特别说明，选择版本号两位为 70 开头的固件进行升级；否则将引
发未知问题，带来不必要的麻烦。

◈ 串口固件升级
  当固件有新增新功能，或有升级解决 BUG 版本后，用户可以通过串口实现升级，以解决问题，使用新功能。
使用前需要连接上串口，然后点击“固件选择”，选择相应的固件，点击打开后将会在固件名称处显示固件名，
确认无误后，再点击固件升级按钮，等待升级进度条完成，也可通过串口界面观察是否完成升级。

                          第 43 页 共 45 页

             深圳市达妙科技有限公司 DM-J4310-2EC V1.1 使用说明书 V1.2

◈ CAN 固件升级
  Bootlaoder 版本在 3.2.0.5 及以上支持使用 CAN 进行固件升级，波特率为驱动板配置的波特率，支持
USB 转 CAN 及 USB 转 CAN FD 进行升级。使用前需要连接上 CAN，确保 CAN 通讯正常，接着在 USB 模式处，
将 UART 切换成 CAN，并在左侧框中填入要升级的电机 ID，如总线不存在，则会有相应的提示，如下：

                            第 44 页 共 45 页

          深圳市达妙科技有限公司 DM-J4310-2EC V1.1 使用说明书 V1.2

  若连接成功，则无提示。
  然后点击“固件选择”，选择相应的固件，点击打开后将会在固件名称处显示固件名，确认无误后，再点
击固件升级按钮，等待升级进度条完成，也可通过串口界面观察是否完成升级。

  升级完成后，串口界面会有相应的提示：

                         第 45 页 共 45 页

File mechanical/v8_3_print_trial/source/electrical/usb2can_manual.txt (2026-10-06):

DM-USB2CANFD Dual 模块
使用说明书 V1.0 2026.03.23

       日期               版本     变更内容

     2026.03.23         V1.0   初版创建

                     深圳市达妙科技有限公司 DM-USB2CANFD Dual 模块使用说明书 V1.0

目录
 一、免责声明. ................................................................................................................................... 3
 二、产品介绍. ................................................................................................................................... 3
 三、接口及线序说明.......................................................................................................................... 3
 四、尺寸及安装................................................................................................................................. 4
 五、指示灯状态................................................................................................................................. 5
 六、模块使用说明. ............................................................................................................................ 5
 ( 一 ) 连接上位机. .............................................................................................................................. 5
 ( 二 ) 查看设备版本............................................................................................................................ 6
 ( 三 ) USB2UART 功能. ...................................................................................................................... 6
 ( 四 ) 配置 CAN 通道波特率. ............................................................................................................... 7
 ( 五 ) 收发报文................................................................................................................................... 8
 ( 六 ) 总线利用率监控....................................................................................................................... 10
 ( 七 ) 切换 CAN 通道. ....................................................................................................................... 10
 ( 八 ) 设备固件升级.......................................................................................................................... 11
 七、SocketCAN 使用说明................................................................................................................ 12
 ( 一 ) 安装必要模块.......................................................................................................................... 12
 ( 二 ) 插入设备后查看....................................................................................................................... 12
 ( 三 ) 配置通道波特率以及模式......................................................................................................... 13
 ( 四 ) 开启通道................................................................................................................................. 14
 ( 五 ) 外部回环测试.......................................................................................................................... 14
 八、二次开发说明. .......................................................................................................................... 15
 九、性能压测展示. .......................................................................................................................... 15

                                                           第 2 页 共 15 页

          深圳市达妙科技有限公司 DM-USB2CANFD Dual 模块使用说明书 V1.0

一、免责声明
  感谢您购买达妙科技 DAMIAO DM-USB2CANFD Dual 模块。在使用本产品之前，请仔细阅读并遵循本文
及达妙科技提供的所有安全指引，否则可能会给您和周围的人带来伤害，损坏本产品或其他周围物品。一旦使
用本产品，即视为您已经仔细阅读本文档，理解、认可和接受本文档及本产品所有相关文档的全部条款和内容。
您承诺仅出于正当目的使用本产品。您承诺对使用本产品以及可能带来的后果负全部责任。达妙科技对于直接
或间接使用本产品而造成的损坏、伤害以及任何法律责任不予负责。
  DAMIAO 是深圳市达妙科技有限公司在产品上使用的商标。本文出现的产品名称、品牌等，均为其所属公
司的商标。本产品及手册为深圳市达妙科技有限公司版权所有。未经许可，不得以任何形式复制翻印。本文档
及本产品所有相关的文档最终解释权归深圳市达妙科技有限公司所有。如有更新，恕不另行通知。

二、产品介绍
  本产品是一款高性能 USB 转双通道 CAN FD 通信模块，专为工业自动化、汽车电子、智能交通及嵌入式
开发等高可靠性通信场景设计。模块支持两路独立 CAN FD 通道，兼容传统 CAN 2.0B 协议，最高数据速率可
达 5 Mbps，显著提升总线通信效率。
  集成 USB High-Speed（USB HS）接口，配合优化驱动与硬件缓冲机制，实现百万帧连续收发不丢包的
稳定性能，满足严苛实时通信需求。同时，模块还支持 USB 转 UART 功能，一机多用，灵活适配串口调试、
设备升级等多种应用场景。
  即插即用，支持 Windows/Linux/macOS 主流操作系统，并提供丰富的 API 与 SDK，便于快速集成与二
次开发。是工程师进行 CAN FD 总线测试、数据分析、网关开发的理想工具。

三、接口及线序说明

                          第 3 页 共 15 页

          深圳市达妙科技有限公司 DM-USB2CANFD Dual 模块使用说明书 V1.0

序号 - 接口名称            接口标注                接口类型              说明

                                                     用于给模块供电以及连
① - 电源及通信接口                               Type-C
                                                     接上位机进行通信。

 ② -UART 接口                              GH1.25 3P   用于接其他串口设备

                                                     用于连接 CAN 网络总
③④ -CAN 通信接口                             GH1.25 2P
                                                     线，收发 CAN 报文

                                                     CAN 总线 120R 终端电
⑤ - 终端电阻开关                                  —        阻开关，向下拨至 ON
                                                     为打开

四、尺寸及安装

                          第 4 页 共 15 页

          深圳市达妙科技有限公司 DM-USB2CANFD Dual 模块使用说明书 V1.0

五、指示灯状态

    序号 - 指示灯               灯状态                    灯语

                          蓝灯闪烁                 未连接上位机

   ① - 系统运行状态灯            绿灯闪烁                 已连接上位机

                          红灯闪烁                   存在错误

                          蓝灯常亮                  通道已使能

 ②③ -CAN 通道工作状态灯          蓝灯熄灭                  通道已失能

                          蓝灯闪烁                 通道正在收发

六、模块使用说明

( 一 ) 连接上位机

 此模块只支持 2.1.5.x 版本及以上上位机，使用前请注意上位机版本。
 设备连接流程如下：
 1. 插入设备：将设备连接至 PC，打开上位机软件；
 2. 刷新设备：如软件匹配到可用设备会自动选择串口号；
 3. 打开串口：点击序号②的【打开串口】按钮完成连接端口号；
 4. 状态确认：成功连接后，设备指示灯由蓝灯闪烁变为绿灯闪烁。

                          第 5 页 共 15 页

           深圳市达妙科技有限公司 DM-USB2CANFD Dual 模块使用说明书 V1.0

( 二 ) 查看设备版本

  在连接上位机的情况下按下 F9 快捷键呼出模块固件升级窗口，点击读取版本即可读取当前模块固件版本。

( 三 ) USB2UART 功能

  本模块提供 USB2UART 功能，通过 USB 发送和接收的数据都直接转发到 UART 接口，无其他协议处理，
支持常用的串口助手。当双方设备处于相同波特率时，使用上位机的串口助手查看数据可正常接收。如果双方
波特率不同，则无法显示出错误的内容。

                           第 6 页 共 15 页

                深圳市达妙科技有限公司 DM-USB2CANFD Dual 模块使用说明书 V1.0

( 四 ) 配置 CAN 通道波特率

  1.CAN2.0 模式
  ① 在主界面按下 F2 快捷键打开设备配置窗口；
  ② 切换工作模式：将设备通信类型设置为 CAN2.0；
  ③ 配置波特率：选择 CAN 波特率（支持 1Mbps、500kbps、250kbps、200kbps、125kbps、100kbps
等常用波特率）；
  ④ 应用配置：点击更新配置按钮。

                                第 7 页 共 15 页

              深圳市达妙科技有限公司 DM-USB2CANFD Dual 模块使用说明书 V1.0

 2.CANFD 模式
 ① 在主界面按下 F2 快捷键打开设备配置窗口；
 ② 切换工作模式：将设备工作模式设置为 FDCAN；
 ③ 配置波特率：
 ・ 仲裁域波特率：最大支持 1Mbps（可 1Mbps/500kbps/250kbps/200kbps/125kbps/100kbps 等）；
 ・ 数据域波特率：最大支持 5Mbps（可选 5Mbps/4Mbps/2.5Mbps/2Mbps/1Mbps 等）；
 ④ 应用配置：点击更新配置按钮。

( 五 ) 收发报文

 CAN 界面如上图所示：
 序号①：帧数据长度配置框；
 序号②：帧数据配置框（输入十六进制数据，禁止使用中文输入，两个位数据之后会自动填充空格）；
 序号③：帧 ID 配置框，标准帧最大 7FF（11 位），拓展帧最大 1FFFFFFF（29 位）；
 序号④：数据递增勾选框，勾选后在报文发送时数据低字节会进行递增操作，递增单位为 1；
 序号⑤：ID 递增勾选框，勾选后在报文发送时 ID 会进行递增操作，递增单位为 1；
 序号⑥：发送次数配置框，当输入 -1 时为无限发送，需要手动点击停止按钮停止发送；
 序号⑦：定时发送时间配置框，当配置为 0 时为无间隔发送，CAN 报文会以最快的速度发送出去；
 序号⑧：帧格式复选框，支持选择标准帧和拓展帧；

                              第 8 页 共 15 页

         深圳市达妙科技有限公司 DM-USB2CANFD Dual 模块使用说明书 V1.0

  序号⑨：帧类型复选框，支持选择数据帧和远程帧，值得注意的是在 FDCAN 下没有远程帧；
  序号⑩：CAN 报文发送按钮；
  序号⑪：停止发送按钮，该按钮可中断当前的发送任务；
  序号⑫：导出数据按钮，支持导出接收和发送的 CAN 报文为 CSV 格式；
  序号⑬：通道占用率查看按钮；
  序号⑭：波特率切换使能（数据段波特率高于仲裁段时需开启）。
  下图是连续发送 10 帧标准帧报文同时进行数据递增和 ID 递增的效果，上位机可对发送的报文类型、时间
戳、格式、ID、发送方向、数据长度和内容进行监控。

                         第 9 页 共 15 页

           深圳市达妙科技有限公司 DM-USB2CANFD Dual 模块使用说明书 V1.0

( 六 ) 总线利用率监控

 当设备处于发送状态时，点击 CAN 界面的左下角通道占用率按钮即可呼出占用率曲线。

( 七 ) 切换 CAN 通道

 切换 CAN 通道时可以检查对于的通道指示灯是否亮起，亮起说明通道使能成功。

                           第 10 页 共 15 页

             深圳市达妙科技有限公司 DM-USB2CANFD Dual 模块使用说明书 V1.0

 ( 八 ) 设备固件升级

  固件升级推荐使用官方的通用升级工具进行升级。
  工具下载地址：https://gitee.com/kit-miao/dm-tools/tree/master/USB2CANFD%E9%80%9A%E7%
94%A8%E5%8D%87%E7%BA%A7%E5%B7%A5%E5%85%B7
    1. 打开工具并连接设备

  2. 选择目标固件

  3. 等待升级

                                 第 11 页 共 15 页

                 深圳市达妙科技有限公司 DM-USB2CANFD Dual 模块使用说明书 V1.0

   4. 查看设备版本
   等待进度条读取完成后，重新打开设备查看版本号是否为目标固件版本。

 七、SocketCAN 使用说明
   在 使 用 SocketCAN 之 前， 需 要 将 模 块 默 认 的 出 厂 固 件 更 换 成 socketcan 固 件， 通 过 上 文 中 设 备 固
件升级章节的操作进行固件更换。使用此特殊固件之前需检查 Linux 内核版本，内核版本低于 6.8 的（如
Ubuntu20）需要进行驱动更换，否则可能无法使用 canfd 功能。
   固件获取地址：
   https://gitee.com/kit-miao/dm-tools/tree/master/USB2CANFD_Dual/%E5%9B%BA%E4%BB%B6/
socketcan

 ( 一 ) 安装必要模块

     sudo modprobe can
     sudo modprobe can_raw
     sudo modprobe can_dev

 ( 二 ) 插入设备后查看

     sudo ip link show

   输入完此命令查看是否存在 can0 以及 can1 设备。

                                    第 12 页 共 15 页

                深圳市达妙科技有限公司 DM-USB2CANFD Dual 模块使用说明书 V1.0

 ( 三 ) 配置通道波特率以及模式

  在配置通道模式以及波特率之前需确保当前通道处于 down 模式，配置前可以输入下列指令来配置成
down 模式。

   sudo ip link set can0 down
   sudo ip link set can1 down

  这里以配置仲裁段 1M 波特率 ( 采样点 75%) 以及数据段 5M 波特率（采样点为 87.5%）为例子，输入下
面指令。

   sudo ip link set can0 type can \
       bitrate 1000000 \
       dbitrate 5000000 \
       sample-point 0.75 \
       dsample-point 0.875 \
       fd on

   sudo ip link set can1 type can \
       bitrate 1000000 \
       dbitrate 5000000 \
       sample-point 0.75 \
       dsample-point 0.875 \
       fd on

  配置完后可以输入下面的指令来查看配置是否生效。

   sudo ip -d link show can0
   sudo ip -d link show can1

                                      第 13 页 共 15 页

               深圳市达妙科技有限公司 DM-USB2CANFD Dual 模块使用说明书 V1.0

  P.S. 如需将通道配置成 CAN2.0 模式可以将 fd on 改为 fd off 开启通道。

( 四 ) 开启通道

   sudo ip link set can0 up
   sudo ip link set can1 up

  输入完上面指令后可以观察到模块的两个通道指示灯亮起。

( 五 ) 外部回环测试

  按照上一步图中的模块接线，并将终端电阻接入，使用 cansend 指令以及 candump 指令来查看两个通
道的收发情况。
  下面以 can0 通道往 can1 通道发送为例。
  打开两个终端分别输入以下两个指令：

   sudo candump can1 -t a

  注：-t a 代表绝对时间戳

   sudo cansend can0 123##91122334455667788

  效果如下：

                                   第 14 页 共 15 页

             深圳市达妙科技有限公司 DM-USB2CANFD Dual 模块使用说明书 V1.0

八、二次开发说明
 二次开发使用官方的 DM_DeviceSDK，目前只提供了 Cpp 版本。
 SDK 获取地址 :https://gitee.com/kit-miao/dm-tools/tree/master/DM_DeviceSDK
 具体使用实例请查看对应的例程以及 Readme 说明。

九、性能压测展示
 [5M 百万帧收发 CANFD 模式下 0DLC 峰值 36000+FPS 丢包率 :0%]

                                   第 15 页 共 15 页

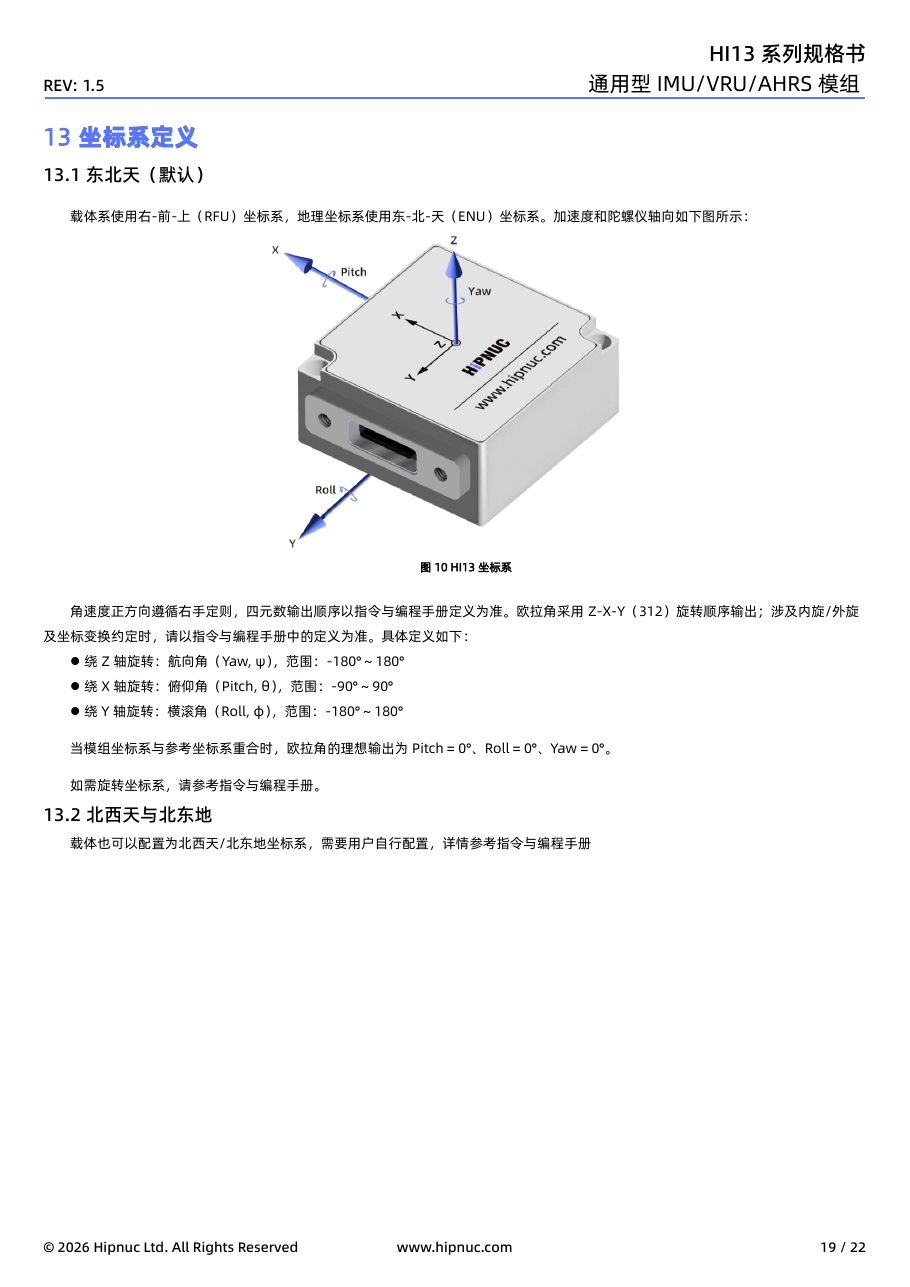
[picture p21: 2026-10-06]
mechanical/v8_3_print_trial/baseline_v81/source/hi13r2/datasheet-19.png

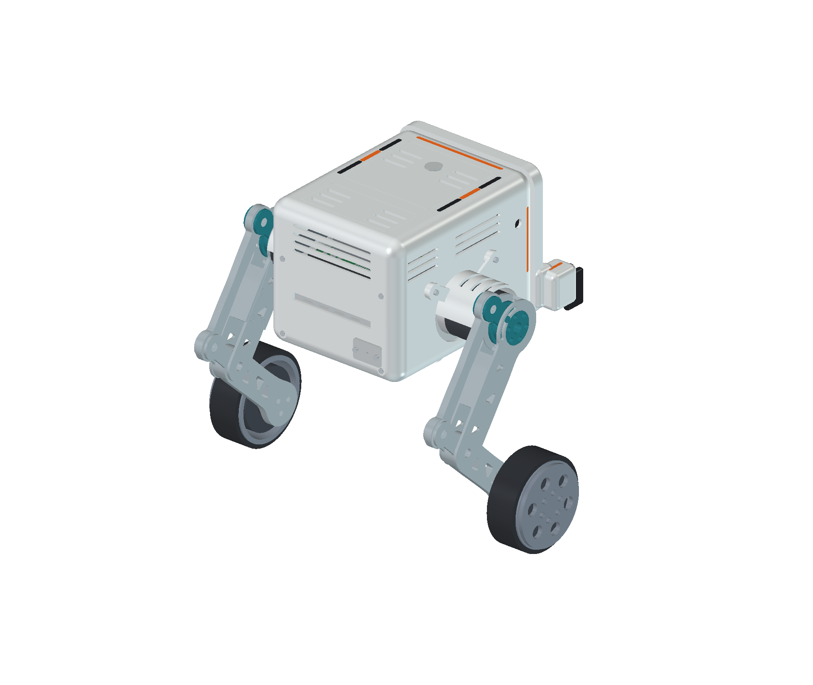
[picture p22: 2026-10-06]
mechanical/v8_3_print_trial/previews/assembly_rear.png

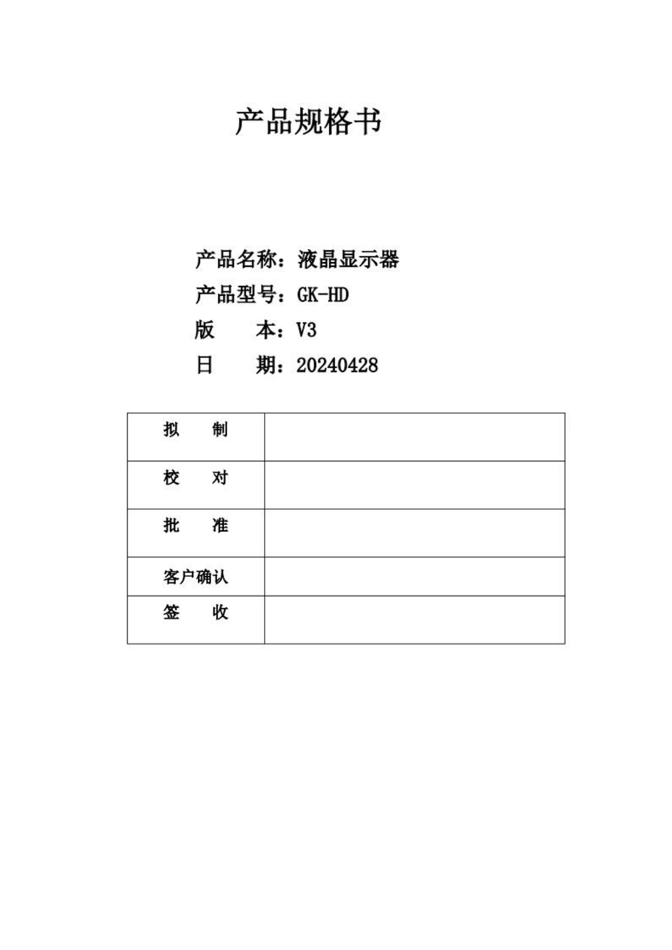
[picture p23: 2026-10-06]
mechanical/v8_3_print_trial/baseline_v81/source/display/page-1.png

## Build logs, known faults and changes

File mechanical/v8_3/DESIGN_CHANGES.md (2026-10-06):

# V8.3 外观修改与试装

根据用户提供的正视及等轴工业设计图调整外壳。尺寸沿用 V8.2 的真实装配基准，未按渲染图缩放电机、显示屏或相机。主壳和后盖采用真实三维外 R16、内 R13 圆角，平面壁厚仍为 3 mm；沿机身前后方向的长棱在维修分缝两侧连续。前白护唇外轮廓 R18、前缘 R2.5，外包络宽170×高161 mm，向后延伸至X109.5以与大圆角壳体可靠相连。

## 修改范围

|编号|零件|本次变化|
|---|---|---|
|P05|前主壳|增加一体圆角白色前护唇；两侧固定小手与壳体连续相连；顶部和侧面浅涂装槽；格栅端部圆滑化|
|P06|后检修壳|顶部浅轮廓槽和格栅端部圆滑化；背部 USB、充电口和全部安装结构保留|
|P07|屏幕相机前脸板|黑色前脸、低矮胶囊形相机装饰圈、两条橙色浅涂装槽；原屏幕开口、相机开口、所有安装孔不变|

其余零件，包括左右腿、承力机架、肩罩、电池及电子设备安装、走线出口和固定件均保持 V8.2 几何与位置。没有增加螺钉、轴承或运动关节。两只小手只是固定装饰结构，无夹持、支撑机器人或承受跌落载荷的用途。

底部在R16外曲面以内保留一体2 mm内搭边（Z−52至−50），开口170×140 mm，顶面仍贴合原金属底板下表面；安装孔和维修分缝插接间隙保留。这避免仅扩大圆角后丢失原底板搭接，而不把外侧重新做成方边。

白、黑和橙色为表面涂装建议。它们不表示增加灯、透光件或另购装饰硬件。前壳与小手同次打印；单色打印后可按实际浅槽涂色。每只圆角护套为 35×29.2×41 mm（X/Y/Z）、外圆角 R6.5、套壁 4.5 mm；每根手指25×7.4×39 mm（X/Y/Z），指间净空4.4 mm、边缘 R3.3。两手外边缘总宽 208 mm，增加5 mm外圈裙边后约218 mm。相机打印支架建议黑色材料或哑黑涂装，避免浅色衬底出现在开口周围。

## 装配与打印

- P05按打印方向的包络约161×208×193 mm，可容纳于220×220×250 mm打印空间；加5 mm裙边后较宽方向约218 mm。尺寸为毫米，不缩放。
- P05 的维修分缝面朝下放置；手套前开口和双指附近采用可移除支撑。手部位于前脸左右外侧，不挡屏幕，也不挡前脸模块沿前方取出。
- P06 维修分缝面朝下；USB 托架局部需要支撑。保持原后壳拆卸顺序。
- P07 后安装平面朝下；胶囊形相机圈高出原前脸 1.4 mm 并朝上打印，避免大面积板面悬空。安装孔贯穿打印方向，首件清孔后再装螺钉。
- 建议先打印孔槽与薄壁试片，再打印主壳；模型保持名义毫米尺寸，不统一缩放补偿。
- 先完成前脸模块和机内模块预装；固定前主壳，再把前脸模块沿 +X 从前方装入并锁紧原四颗 M3×12；后壳与背部接口模块仍按 V8.2 顺序装配。
- 相机圈未缩小原相机开口，保留真实 D435 模型和四个原连接孔；首装仍应使用实际深度图检查镜头附近饰面是否反射或进入边缘视场。

## 检查范围

`shell_validation.json` 记录：变更壳体对全部实体的名义干涉检查；腿长 100、180、215 mm，分别配合β=−15°、0°、+15°的九个离散姿态；前脸模块沿 +X 抽出的十个离散位置；V8.2 其余对象几何、位置和运动表达式的一致性核对。β角仅为本次几何诊断抽样，不是已认证的可运行角度范围。

离散位置检查不是连续运动或线束柔性检查。打印版金属替代件用于无动力试装；不据此宣称承载、跳跃或跌落强度合格。

## 可复现来源

- 输入：`../v8_2/wheel_leg_v8_2.FCStd`。
- 构建：`../../tools/build_v83_shell.py`（从仓库根目录以系统 FreeCAD Python 运行）。
- 渲染：`../../tools/render_v83_robot.py`。
- CAD API 参考：[FreeCAD Part::TopoShape 官方文档](https://freecad.github.io/SourceDoc/d8/ded/classPart_1_1TopoShape.html)。

装配体和渲染图是实际 CAD 几何，没有使用生成式图片替代制造结构。

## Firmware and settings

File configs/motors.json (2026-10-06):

{
  "j4310": {
    "name": "DM-J4310-2EC V1.1",
    "reference_dir": "references/DM-J4310-2EC",
    "mass_kg": 0.3,
    "outer_diameter_m": 0.057,
    "body_length_m": 0.046,
    "rated_voltage_v": 24.0,
    "maximum_voltage_v": 28.0,
    "rated_torque_nm": 3.0,
    "peak_torque_nm": 7.0,
    "rated_speed_rpm": 120.0,
    "no_load_speed_rpm": 200.0,
    "gear_ratio": 10.0,
    "pole_pairs": 14,
    "phase_inductance_h": 0.00034,
    "phase_resistance_ohm": 0.65,
    "slots": 24,
    "encoder_bits": 14,
    "encoder_count": 2,
    "control_interface": "CAN 1 Mbps",
    "tuning_interface": "UART 921600 bps",
    "output_flange_diameter_m": 0.05,
    "output_register_diameter_m": 0.0243,
    "mounting_bolt_circle_m": 0.038,
    "notes": "24 V version; the manual also lists a separate 48 V variant.",
    "step_model_path": "references/DM-J4310-2EC/3D模型/DM-J4310-2EC-V1.1_3d_20260228_1.stp",
    "mesh_asset": "assets/meshes/DM-J4310-2EC-V1.1.stl",
    "mesh_axis_center_y_m": 0.0225
  },
  "h6215": {
    "name": "DM-H6215",
    "reference_dir": "references/DM-H6215",
    "mass_kg": 0.36,
    "outer_diameter_m": 0.068,
    "body_length_m": 0.0445,
    "rated_voltage_v": 24.0,
    "maximum_voltage_v": null,
    "rated_torque_nm": 1.0,
    "peak_torque_nm": 2.0,
    "rated_speed_rpm": null,
    "no_load_speed_rpm": null,
    "gear_ratio": null,
    "pole_pairs": null,
    "phase_inductance_h": null,
    "phase_resistance_ohm": null,
    "slots": null,
    "encoder_bits": null,
    "encoder_count": null,
    "control_interface": "CAN 1 Mbps",
    "tuning_interface": null,
    "output_flange_diameter_m": 0.033,
    "output_register_diameter_m": 0.022,
    "mounting_bolt_circle_m": 0.028,
    "notes": "Mass, rated torque and peak torque are user-provided. The drawing also shows a rear Ø17.50 mm mounting circle and 3xM3 holes; no speed table was found.",
    "step_model_path": "references/DM-H6215/3D模型/6215_轮毂电机3D模型20240821.stp",
    "mesh_asset": "assets/meshes/DM-H6215.stl",
    "mesh_axis_center_y_m": 0.01975
  }
}

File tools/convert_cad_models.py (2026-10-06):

"""Convert the supplied motor STEP assemblies into MuJoCo visual meshes.

The preferred converter is the FreeCAD Python executable supplied with the
application. ``auto`` falls back to FreeCAD's bundled Gmsh executable when
FreeCAD cannot start in a headless environment. Both paths read the original
STEP files; the generated STL uses millimetres and is a visual reference. These are historical visual assets; the current
MuJoCo project generates its motor visuals procedurally and does not load them.
"""
from __future__ import annotations

import argparse
import json
import os
import struct
import subprocess
import sys
from pathlib import Path

PROJECT_DIR = Path(__file__).resolve().parents[1]
FREECAD_PYTHON = Path("/Applications/FreeCAD.app/Contents/Resources/bin/python")
GMSH = FREECAD_PYTHON.with_name("gmsh")
MOTOR_SPECS = json.loads((PROJECT_DIR / "configs/motors.json").read_text())


def _source_and_output(motor: str, output_dir: Path) -> tuple[Path, Path]:
    spec = MOTOR_SPECS[motor]
    if not spec.get("step_model_path") or not spec.get("mesh_asset"):
        raise ValueError(f"{spec['name']} CAD path metadata is incomplete.")
    source = PROJECT_DIR / spec["step_model_path"]
    if not source.is_file():
        raise FileNotFoundError(f"STEP source does not exist: {source}")
    return source, output_dir / Path(spec["mesh_asset"]).name


def _check_output(path: Path) -> None:
    if not path.is_file() or path.stat().st_size < 1024:
        raise RuntimeError(f"CAD conversion produced no usable mesh: {path}")
    # MuJoCo 3.2.7 limits an STL asset to 200,000 triangular faces. Keep
    # conversion failures close to the source command instead of discovering
    # the limit only when compiling the MJCF model.
    with path.open("rb") as stream:
        stream.seek(80)
        count_data = stream.read(4)
    if len(count_data) == 4:
        face_count = struct.unpack("<I", count_data)[0]
        if face_count == 0 or face_count > 200_000:
            raise RuntimeError(
                f"STL face count {face_count} is outside MuJoCo's limit: {path}")


def _export_with_freecad(step_path: Path, output_path: Path,
                         deviation_mm: float) -> None:
    """Run inside FreeCAD Python and export all imported STEP shapes as one STL."""
    resource_dir = Path(sys.executable).resolve().parent.parent
    for module_dir in (resource_dir / "lib", resource_dir / "Ext",
                       resource_dir / "Mod"):
        if str(module_dir) not in sys.path:
            sys.path.insert(0, str(module_dir))
    import FreeCAD as App  # type: ignore[import-not-found]
    import Import  # type: ignore[import-not-found]
    import MeshPart  # type: ignore[import-not-found]
    import Part  # type: ignore[import-not-found]

    document_name = "motor_step_export"
    doc = App.newDocument(document_name)
    try:
        Import.insert(str(step_path), doc.Name)
        doc.recompute()
        shapes = [obj.Shape for obj in doc.Objects
                  if hasattr(obj, "Shape") and not obj.Shape.isNull()]
        if not shapes:
            raise RuntimeError(f"No solid shapes found in {step_path}")
        compound = Part.makeCompound(shapes)
        mesh = MeshPart.meshFromShape(
            Shape=compound,
            LinearDeflection=deviation_mm,
            AngularDeflection=0.3,
            Relative=False,
        )
        output_path.parent.mkdir(parents=True, exist_ok=True)
        mesh.write(str(output_path))
    finally:
        App.closeDocument(doc.Name)


def _run_freecad(motor: str, output_dir: Path, deviation_mm: float) -> None:
    if not FREECAD_PYTHON.is_file():
        raise FileNotFoundError(f"FreeCAD Python not found: {FREECAD_PYTHON}")
    command = [
        str(FREECAD_PYTHON), str(Path(__file__).resolve()),
        "--engine", "freecad", "--motor", motor,
        "--output-dir", str(output_dir),
        "--deviation-mm", str(deviation_mm),
    ]
    resource_dir = FREECAD_PYTHON.parent.parent
    env = os.environ.copy()
    module_paths = [resource_dir / "lib", resource_dir / "Ext",
                    resource_dir / "Mod"]
    existing_pythonpath = env.get("PYTHONPATH", "")
    env["PYTHONPATH"] = os.pathsep.join(
        [str(path) for path in module_paths] +
        ([existing_pythonpath] if existing_pythonpath else [])
    )
    result = subprocess.run(command, capture_output=True, text=True,
                            timeout=300, check=False, env=env)
    if result.returncode != 0:
        details = (result.stderr or result.stdout).strip().splitlines()
        tail = "\n".join(details[-8:])
        raise RuntimeError(f"FreeCAD conversion failed for {motor}:\n{tail}")


def _run_gmsh(motor: str, output_dir: Path,
              max_element_mm: float | None) -> None:
    if not GMSH.is_file():
        raise FileNotFoundError(f"Gmsh fallback not found: {GMSH}")
    source, output = _source_and_output(motor, output_dir)
    command = [
        str(GMSH), "-v", "1", "-bin", "-format", "stl", "-2", "-o",
        str(output), str(source),
    ]
    if max_element_mm is not None:
        command[6:6] = ["-clmax", str(max_element_mm)]
    result = subprocess.run(command, capture_output=True, text=True,
                            timeout=600, check=False)
    if result.returncode != 0:
        details = (result.stderr or result.stdout).strip().splitlines()
        tail = "\n".join(details[-8:])
        raise RuntimeError(f"Gmsh conversion failed for {motor}:\n{tail}")
    _check_output(output)


def convert_one(motor: str, engine: str, output_dir: Path,
                deviation_mm: float, max_element_mm: float | None) -> str:
    source, output = _source_and_output(motor, output_dir)
    output_dir.mkdir(parents=True, exist_ok=True)
    if engine in ("auto", "freecad"):
        try:
            if engine == "freecad":
                _export_with_freecad(source, output, deviation_mm)
            else:
                _run_freecad(motor, output_dir, deviation_mm)
            _check_output(output)
            return "FreeCAD"
        except (FileNotFoundError, RuntimeError, subprocess.SubprocessError) as exc:
            if engine == "freecad":
                raise
            print(f"FreeCAD unavailable for {motor}; using Gmsh fallback: {exc}")
    _run_gmsh(motor, output_dir, max_element_mm)
    return "Gmsh fallback"


def main() -> None:
    parser = argparse.ArgumentParser(description=__doc__)
    parser.add_argument("--motor", choices=("all", *MOTOR_SPECS), default="all")
    parser.add_argument("--engine", choices=("auto", "freecad", "gmsh"),
                        default="auto")
    parser.add_argument("--output-dir", type=Path,
                        default=PROJECT_DIR / "assets/meshes")
    parser.add_argument("--deviation-mm", type=float, default=0.1,
                        help="FreeCAD linear tessellation deviation in mm")
    parser.add_argument("--gmsh-max-element-mm", type=float, default=1.1,
                        help="Gmsh maximum surface element size in mm (default: 1.1)")
    args = parser.parse_args()
    if args.deviation_mm <= 0 or (args.gmsh_max_element_mm is not None
                                  and args.gmsh_max_element_mm <= 0):
        parser.error("mesh tolerances must be positive")

    motors = tuple(MOTOR_SPECS) if args.motor == "all" else (args.motor,)
    for motor in motors:
        engine = convert_one(motor, args.engine, args.output_dir,
                             args.deviation_mm, args.gmsh_max_element_mm)
        _, output = _source_and_output(motor, args.output_dir)
        print(f"{motor}: {engine}; wrote {output.resolve()}")


if __name__ == "__main__":
    main()
